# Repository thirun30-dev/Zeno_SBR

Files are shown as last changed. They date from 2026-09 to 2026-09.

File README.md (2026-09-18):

🤖 ZENO — Self-Balancing Robot

<p align="center">
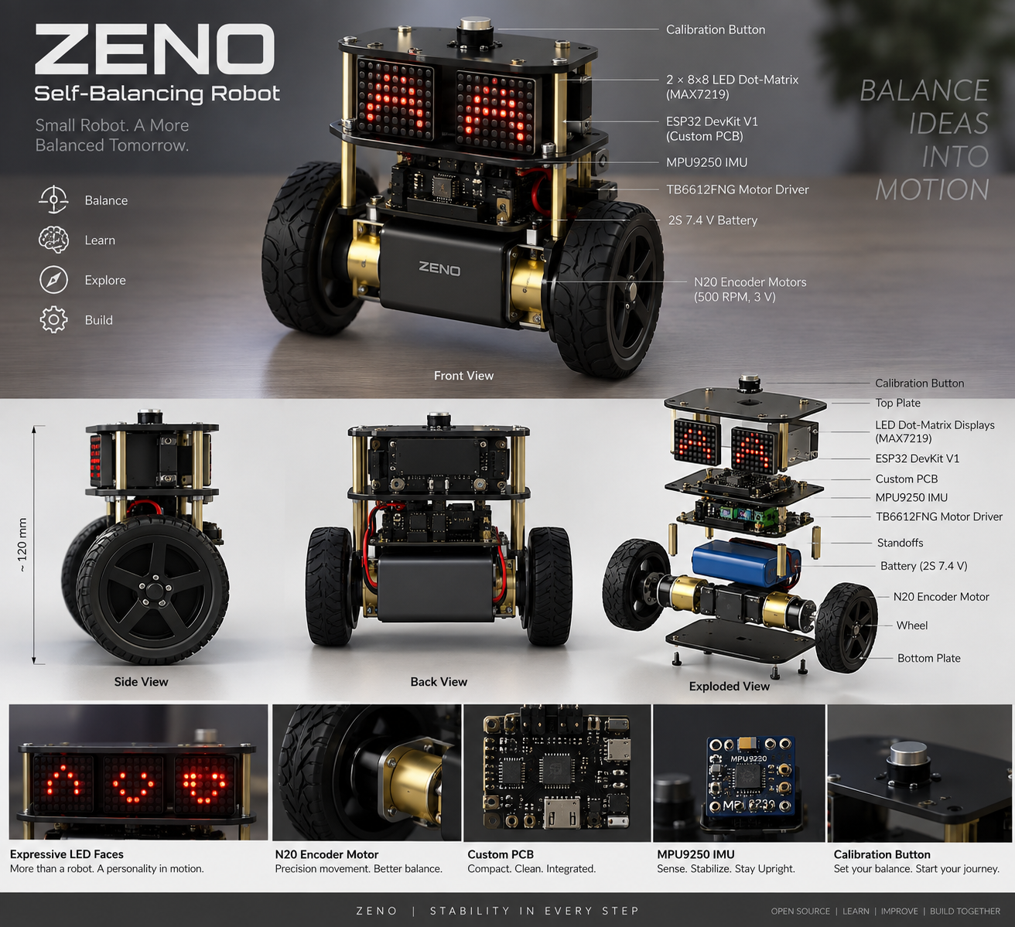
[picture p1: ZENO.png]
ZENO Self-Balancing Robot
  
</p>

<p align="center">
  <b>Balance Ideas Into Motion.</b><br>
  ESP32 • MPU9250 • PID Control • N20 Encoder Motors • TB6612FNG • Custom CAD/PCB • Web Dashboard
</p>

📌 About ZENO

ZENO is a compact two-wheeled self-balancing robot developed as a hands-on platform for embedded systems, feedback control, sensor fusion, motor control, mechanical design, PCB development, and robot–user interaction.

The robot uses an ESP32 DevKit V1 as the main controller, an MPU9250 IMU to estimate body tilt, and two N20 3 V 500 RPM geared DC motors with encoders driven by a TB6612FNG dual motor driver. A PID controller continuously calculates the correction required to keep the robot close to its calibrated upright angle.

The repository also contains the current mechanical design files, 3D-printable parts, a PCB placement/connectivity draft, individual hardware test programs, and the main balancing firmware.

✨ Key Features

Two-wheel real-time self-balancing

ESP32-based embedded control

MPU9250 accelerometer and gyroscope sensing

Complementary-filter angle estimation

PID balance control

N20 encoder motor drive

Serial-command control and PID tuning

IMU calibration routine

Forward, reverse, left, and right movement commands

Automatic motor shutdown beyond a configured fall angle

Modular two-layer mechanical chassis

Custom PCB development files

3D-printable motor cap, base, top deck, and threaded spacers

MAX7219 LED matrix hardware provision for expressive robot eyes

Web-dashboard concept for telemetry, visualization, control, and tuning

🧠 Control Architecture

MPU9250 IMU
    │
    ▼
Accelerometer + Gyroscope
    │
    ▼
Complementary Filter
    │
    ▼
Estimated Pitch Angle
    │
    ▼
Target Angle − Current Angle
    │
    ▼
PID Controller
    │
    ▼
Motor PWM + Direction
    │
    ▼
TB6612FNG Motor Driver
    │
    ▼
N20 Encoder Motors
    │
    └──────── Encoder Feedback ────────┐
                                      │
                                      ▼
                                 ESP32 Control

The current firmware uses starting PID values of:

Kp = 22.0
Ki = 0.0
Kd = 0.85

These are starting values only and must be tuned for the final ZENO mechanical configuration.

🔩 Main Hardware

Component

Specification

Main controller

ESP32 DevKit V1

IMU

MPU9250

Motor driver

TB6612FNG

Motors

2 × N20 3 V 500 RPM geared DC motors

Feedback

Motor encoder signals

Robot eyes

2 × MAX7219 8×8 LED matrix modules

Battery system

Protected 2S battery pack

Nominal battery voltage

7.4 V

Fully charged voltage

8.4 V

ESP32 / display rail

Regulated 5 V

Motor rail

Regulated nominal 3 V

Logic rail

ESP32 3.3 V

PCB outline

Approx. 130 × 77 mm

The motor supply and regulator current capability must be selected using the measured motor stall current. Do not power the stated 3 V motors directly from the raw 2S battery.

🔌 ESP32 Pin Mapping

MPU9250

Signal

ESP32

SDA

GPIO 22

SCL

GPIO 23

I2C address

0x68

TB6612FNG

Signal

ESP32

PWMA

GPIO 25

AIN1

GPIO 26

AIN2

GPIO 27

STBY

GPIO 32

BIN1

GPIO 14

BIN2

GPIO 13

PWMB

GPIO 33

Encoder Input Currently Used by Main Firmware

Signal

ESP32

Encoder A

GPIO 19

Encoder B

GPIO 18

🎮 Serial Commands

The main firmware supports interactive control through the Arduino Serial Monitor.

Command

Function

C

Calibrate IMU

B

Enable balancing

S

Stop balancing

F

Move forward

R

Move backward

L

Turn left

T

Turn right

X

Stop movement

P

Print PID values

I

Increase Kp

i

Decrease Kp

O

Increase Ki

o

Decrease Ki

D

Increase Kd

d

Decrease Kd

⚖️ Calibration and Balancing

Before balancing, place ZENO in the intended upright position and send:

C

The firmware calibrates the IMU and establishes the angle reference. Once calibration is complete, balancing can be enabled with:

B

The robot continuously compares the current tilt with the target angle and applies motor corrections. The current firmware contains a 40° fall-angle safety threshold; when the robot exceeds this angle, motor drive is stopped to reduce uncontrolled motion.

🖥️ ZENO Web Dashboard

ZENO is also being developed with a dedicated web dashboard for a more intuitive robot-monitoring and control experience. The dashboard is intended to complement the ESP32 firmware and Serial Monitor rather than replace firmware-side safety logic.

Planned / Supported Dashboard Areas

Animated 3D ZENO introduction

Light and dark themes

Robot connection state

Balance state

Live pitch / tilt angle

Target angle and PID error

Kp, Ki, and Kd visualization

Left and right motor output

Encoder count / wheel-speed telemetry

IMU acceleration and angular velocity

Battery / power status

Calibration control

Start / stop balancing

Manual movement controls

Emergency-stop interface

Real-time telemetry graphs

PID tuning controls

3D robot orientation visualization

Dashboard Data Flow

ZENO Hardware
     │
     ▼
ESP32 Firmware
     │
     ├── IMU Data
     ├── PID Data
     ├── Encoder Data
     ├── Motor Output
     └── System Status
            │
            ▼
     Wi-Fi / WebSocket
            │
            ▼
      ZENO Dashboard
            │
      ┌─────┴─────┐
      ▼           ▼
 Telemetry      Control

Repository note: the uploaded repository snapshot currently contains the firmware, CAD/3D files, PCB draft, and image assets. The dashboard source is not yet included in this snapshot. Add it under a dedicated Dashboard/ or dashboard/ directory when integrating the web application.

🧱 Mechanical Design

ZENO uses a modular two-layer structure.

Base Layer

The lower section is intended to carry:

N20 motors

Wheels

Battery / battery holder

Motor mounting parts

Structural mounting points

Top Layer

The upper section is intended to carry:

Custom PCB

ESP32 DevKit V1

TB6612FNG

MPU9250

Display modules

Calibration button

The repository includes printable and editable mechanical files for the robot base, top deck, N20 motor cap, deck spacers, and assembly references.

🧩 Repository Structure

Zeno_SBR/
│
├── 3D/
│   ├── 3D print/
│   │   ├── ZENO_base.stl
│   │   ├── top_deck.stl
│   │   ├── N20_single_cap_1.STL
│   │   └── deck_spacer_50mm_M3_threaded.stl
│   │
│   ├── ZENO_Base_Mounting_Holes/
│   ├── ZENO_N20_Single_Cap/
│   ├── ZENO_PCB_Draft/
│   └── ZENO_Top_Layer/
│
├── Code/
│   ├── Motor_Test/
│   │   └── Motor_Test.ino
│   ├── MPU9250/
│   │   └── MPU9250.ino
│   └── ZENO_code/
│       └── ZENO_code.ino
│
└── ZENO.png

After adding the web application, a recommended extension is:

├── Dashboard/
│   ├── src/
│   ├── public/
│   ├── package.json
│   └── README.md

📁 Important Repository Files

Code/Motor_Test/Motor_Test.ino

Used to verify TB6612FNG wiring and basic motor direction/control independently of the balancing loop.

Code/MPU9250/MPU9250.ino

Used to test MPU9250 communication, calibration, and orientation measurement separately.

Code/ZENO_code/ZENO_code.ino

Current integrated ZENO balancing firmware containing IMU acquisition, calibration, complementary filtering, PID calculations, motor control, encoder input, serial commands, and fall protection.

3D/3D print/

Contains the primary STL files intended for fabrication/3D printing.

3D/ZENO_PCB_Draft/

Contains the current KiCad placement and connectivity draft.

⚠️ PCB Development Status

The included ZENO Rev A PCB is a placement/connectivity draft and is currently marked:

UNROUTED — NOT FOR FABRICATION

The PCB files must be fully verified before manufacturing. Required work includes:

Verify physical module footprints and pin order

Confirm motor and encoder electrical requirements

Verify ESP32 footprint spacing

Verify connector families and orientation

Add routing, vias, and copper zones

Add a continuous ground reference

Check ESP32 antenna clearance

Verify motor-current trace width

Complete schematic/ERC verification

Run KiCad DRC

Generate and inspect Gerbers only after validation

Do not submit the current PCB draft directly for fabrication.

🚀 Running the Firmware

Install the ESP32 board package in the Arduino IDE.

Connect the ESP32 DevKit V1.

Open:

Code/ZENO_code/ZENO_code.ino

Select the appropriate ESP32 board and COM/serial port.

Compile and upload the firmware.

Open Serial Monitor.

Keep the robot supported safely with wheels free during initial testing.

Send C to calibrate.

Verify angle direction and motor direction before enabling balance mode.

Tune PID values gradually for the final mechanical build.

🧪 Recommended Testing Sequence

1. Verify regulated power rails
        ↓
2. Test MPU9250 communication
        ↓
3. Run Motor_Test.ino
        ↓
4. Confirm both motor directions
        ↓
5. Verify encoder response
        ↓
6. Upload integrated ZENO firmware
        ↓
7. Calibrate IMU
        ↓
8. Verify tilt-angle direction
        ↓
9. Test balancing while physically supported
        ↓
10. Tune PID parameters
        ↓
11. Perform controlled free-balance tests
        ↓
12. Integrate live dashboard telemetry

🛠️ Development Roadmap

Mechanical base design

Top deck design

N20 motor mounting design

M3 threaded spacer design

MPU9250 test firmware

Motor test firmware

Integrated balancing firmware

Serial-based PID adjustment

Fall-angle protection

Initial PCB placement/connectivity draft

Tune PID on the completed mechanical robot

Validate both motor encoders independently

Complete and route PCB

Fabricate and test custom PCB

Integrate MAX7219 eye animations into main firmware

Add Wi-Fi/WebSocket telemetry

Add dashboard source to repository

Connect dashboard to live ESP32 data

Add battery monitoring

Add OTA firmware updates

Add advanced motion/position control

🎯 Applications and Learning Outcomes

ZENO can be used to explore:

Self-balancing robotics

Inverted-pendulum control

Embedded C/C++ programming

ESP32 development

PID control

Sensor fusion

IMU calibration

DC motor control

Encoder feedback

PCB design

CAD and 3D printing

Power-system integration

Web-based robot telemetry

Human–robot interaction

⚠️ Safety

ZENO contains moving motors and a rechargeable battery system. During development:

Verify regulator outputs before connecting electronics.

Use a protected battery pack.

Keep a physical power-disconnect method available.

Do not test balancing near edges or fragile objects.

Support the chassis during initial PID tuning.

Confirm motor direction before enabling closed-loop balancing.

Do not treat a web-based emergency-stop button as a substitute for hardware power isolation.

📈 Project Status

Active Development

The mechanical design, test firmware, integrated balancing firmware, and initial PCB draft are present in this repository. PID tuning, PCB completion, display integration, wireless telemetry, and web-dashboard integration remain active development areas.

📜 Disclaimer

ZENO is an educational and experimental robotics project. Hardware dimensions, electrical connections, PCB footprints, power-system limits, PID parameters, and software should be independently verified before fabrication or operation.

🤝 Contributions

Suggestions, improvements, testing feedback, and contributions are welcome as the ZENO platform develops.

<p align="center">
  <b>ZENO</b><br>
  <i>Balance Ideas Into Motion.</i>
</p>

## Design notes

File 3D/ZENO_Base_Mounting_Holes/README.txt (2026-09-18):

ZENO BASE LAYER — REV B / PROTOTYPE
All dimensions mm. Designed for two N20 encoder motors, the supplied
76 x 41 x 19 battery holder, and nominal 44 diameter x 18 wide wheels.
This is the lower deck; top deck and motor caps are separate parts.

DIMENSIONS
Plate 124 across axle (X) x 96 fore/aft (Y) x 3 thick; corner radius 6.
Battery pocket internal: 41.8 X x 76.8 Y, centred on base.
Pocket wall 3 thick x 8 above plate; overall wall top Z=11.
Holder rests at Z=3; nominal holder top Z=22.
Wire notch 10 wide in +Y pocket wall, bottom Z=4; open upward.
Strap slots at X=+/-26,Y=0: 3 across X x 12 along Y, through plate.
Motor bracket holes: four diameter 3.2 THRU, X=+/-46,Y=+/-11.
Each bracket has 22 mm hole centre spacing along Y.
Left/right bracket centre separation is 92 mm along X.
Hole coordinates: (-46,-11),(-46,11),(46,-11),(46,11).
M3 clearance, not threaded; use washers and nuts beneath base.
Four top-deck standoff holes: diameter 3.2 at X=+/-52,Y=+/-38;
104 x 76 mounting pattern. M3 clearance, not tapped.
Cable passages at X=+/-39,Y=26: 12 along Y x 5 wide rounded slots.
Origin base centre, Z=0 underside; motor shafts lie along X, nominal Y=0.

MOTOR LAYOUT / LIMITS
Use user's modified N20_single_cap.step.SLDPRT as the intended motor cap.
Its exact geometry/hole positions could not be verified in this workflow.
The fixed 22 mm pitch follows the ORIGINAL single-cap design, not a verified
measurement of the modified SLDPRT. Check hole pitch and motor position in
SolidWorks before printing; these holes provide no slot adjustment.
No replacement motor cap is included. Trial-fit the modified cap before
printing the full deck, or overlay its STEP export on this base in SolidWorks.
Nominal motor location per side: gearbox front X=+/-63, gearbox rear +/-54,
rear motor/encoder envelope ends approximately +/-32. Shaft extends to +/-73.
Suggested steel casing clamp band: |X|=40 to 52, centred on bracket holes at 46.
These positions use the previous motor dimensional image; verify casing,
encoder and cap shape physically. Motor and wheel CAD are NOT included.
Keep wheel inner face outside |X|=64 for nominal 2 mm plate-edge clearance;
actual hub insertion and shaft engagement must be measured, not inferred from
44 x 18 wheel size. Do not operate with inadequate shaft engagement.
If shaft axis is approximately Z=9.1, nominal upright underside clearance is
22-9.1=12.9. With a 48 fore/aft half-length, base-ground contact occurs at
roughly 16 degrees pitch on level ground, ignoring fastener protrusions.
Actual axle height, loaded tyre radius and hub position remain unverified.
This is a geometry prototype, not a tested balancing-robot chassis.

ASSEMBLY
Use a <=10-wide nonconductive strap through pocket-side slots and over holder
so it cannot lift out. Keep the loop beneath the base clear of fasteners.
Route battery wires through +Y notch; two outer slots provide cable routing.
Use washers and nuts with M3 motor-cap bolts; lengths depend on modified cap.
Top-layer supports use four M3 standoffs on 104 x 76 centres. Select height
after top-deck component placement; holder top is already Z=22, so leave
additional clearance for cells, strap, wiring and service access.
Pocket and base share a single 3-thick floor; no stacked floor thickness.

PRINT / FILES
Suggested prototype PETG, bottom-down, 0.2 layers, 4 walls, 40-50% infill;
no supports normally required. Verify bed supports 124 x 96 footprint.
Printed clearance holes may need finishing. Test print mounting/pocket regions
or check parts in CAD before committing full print.
ZENO_base.step: single solid, importable into SolidWorks.
ZENO_base.stl: mm, print orientation bottom-down.
base_with_battery_envelope.step: base + simple 41 x 76 x 19 reference block;
block is not a detailed holder or a printable battery component.
layout.svg: dimensioned schematic top layout; use labelled values, not scaling.
preview.png: geometry preview.
build_base.py + battery_pocket_source.step: reproducible CadQuery source.
Validation: single valid solid, STEP/STL exported; physical fit not tested.

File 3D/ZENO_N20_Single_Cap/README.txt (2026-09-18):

ZENO — SINGLE N20 MOTOR CAP / REV B
Units: mm. Single U-shaped part with two rounded tabs, following user reference.
Replaces the previous two-piece bracket. No separate lower clamp is required:
the flat chassis closes the open side and supports the motor.

DIMENSIONS
Overall: 30 wide x 12 along shaft x 14.9 high.
Internal rectangular channel: 10.4 wide x 12.4 high, open both axial ends.
Wall and roof thickness: 2.5.
Mounting tab thickness: 3.0; rounded end radius 4.0.
Two M3 clearance holes: diameter 3.2 THRU, 22 centre-to-centre.
Hole coordinates: X=-11 and +11, Y=0. Shaft direction is Y.
Chassis contact plane: Z=0. Channel ceiling: Z=12.4.

FIT ASSUMPTIONS — CHECK BEFORE PRINTING
User motor drawing shows 10 x 12 gearbox face, 12.2 max body diameter,
9 gearbox length and 22 +/-1 motor/encoder rear envelope.
The motor casing width across flats is not separately specified. Model assumes
10.0 across flats plus 0.4 total clearance. Height uses 12.2 maximum body
height plus 0.2 clearance. Check actual casing width and height with calipers.
The 12-long cap must fit entirely over steel motor casing, clear of exposed
gears, rear endbell, encoder, connector and any protrusions.
This is a geometrically validated prototype, not a physically tested fit.

INSTALLATION
Place motor casing on chassis with its narrow (assumed 10 mm) dimension
across the cap. Install cap over it, rounded tabs down against chassis.
Use a thin compliant liner/shim to eliminate clearance and create a snug grip.
Do not expect the oversized bare channel alone to clamp the motor securely.
Select liner thickness by actual fit; cap should grip before tabs fully seat.
Use two M3 bolts, washers and nuts; bolt length depends on chassis thickness.
For 3 mm chassis, M3x12 is a starting option: verify washer/nut stack and
thread engagement. Snug evenly without deforming motor casing or tabs.
Confirm motor cannot slide or rotate under operating torque.
Print one cap and test fit before producing the second robot motor mount.

FABRICATION AND FILES
Suggested prototype material PETG; layer 0.2; 4 walls; 50% infill.
STL is oriented roof-down / opening-up, resembling reference photo.
Support is required beneath elevated mounting tabs in this orientation.
Clean supports and finish M3 clearance holes with a 3.2 mm drill if necessary.
STEP uses installed coordinates: tabs at bottom, opening toward chassis.
N20_single_cap.step: solid CAD model importable into SolidWorks.
N20_single_cap.stl: print-oriented mesh in mm.
N20_single_cap.svg: CAD view, not a scale drawing.
preview.png: inverted view exposing internal channel.
build_cap.py: editable CadQuery generator, with explicit fit parameters.

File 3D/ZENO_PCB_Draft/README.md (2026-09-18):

# ZENO Rev A — placement and connectivity draft

**UNROUTED. NOT FOR FABRICATION.** No Gerbers or fabrication release are included. Native KiCad loading and DRC were not available in this environment. Open the board directly in KiCad PCB Editor. Nets provide ratsnest connections; there is no graphical .kicad_sch schematic. The XML netlist is supplementary.

## Mechanical plan
130 × 77 × 1.6 mm, two copper layers. Front is y=77; rear is y=0. Proposed 3.2 mm mounting holes: (5,5), (125,5), (5,72), (125,72) mm. Hole spacing 120 × 67 mm is provisional, not matched to chassis. Module sockets use 1 mm drills and 1.7 mm pads provisionally. No connector body courtyards or final housing geometry have been validated. The preview is a placement drawing, not a rendering of a finished routed PCB.

## Electrical decisions
External regulated +5 V enters J7; external regulated nominal 3 V motor power enters J8. Raw 2S battery must not enter either connector. Use upstream protection and regulator current capacity appropriate to measured loads. Do not simultaneously connect external 5 V and USB until the actual DevKit power-path isolation is checked. VM and +5 V share ground but are not connected together. TB6612 logic VCC is +3V3. Check driver suitability against motor stall current and thermal conditions; no stall-current validation has been performed.

Encoder supply is provisionally 3.3 V. If encoder requires 5 V, redesign supply and level conversion before connection. GPIO34/35/36/39 are input-only; external pull-up footprints are provided. Do not infer cable pin order from colours. Motor minus is a bridge output, not ground.

Displays use three 5 V SN74AHCT125 buffer channels. Eye 1 DOUT must return through J5 to eye 2 DIN at J4. Both displays share CLK and CS. This additional return connection is required for independent eyes in a daisy chain. Alternatively wire module-to-module and revise the harness accordingly.

Calibration: J6 pins 1 COM/GND, 2 NO/GPIO4, 3 LED+/5V, 4 LED-/GND. NC unused. LED continuously on with power if purchased LED supports 5 V. Firmware must debounce and allow calibration only when stationary with motor outputs disabled. This button is not a battery disconnect or emergency stop.

IMU: AD0 low selects 0x68 for compatible devices; NCS held high for I2C, FSYNC low. EDA/ECL/INT unused. Verify sensor identity, VCC regulator dropout, and bus pull-ups on actual board. Optional carrier I2C pull-ups R7/R8 are DNP by default.

## Before routing and fabrication
1. Measure ESP32 row spacing (assumed 25.4 mm), TB6612 row spacing (assumed 15.24 mm), and IMU pitch (assumed 2.54 mm). Confirm module face/orientation against every net, especially TB6612 photograph.
2. Identify exact six-pin JST family, pitch, mating PCB header and cable orientation. Current J1/J2 pads are 2.0 mm placeholders, not validated connector footprints.
3. Measure standoffs and switch chassis clearance; confirm motor/encoder voltage and stall current.
4. Replace provisional footprints with verified body outlines/courtyards, add actual ESP32 antenna copper/component keepout on both sides and maintain USB access.
5. Route motor paths short and wide, away from IMU and I2C; size copper for measured current and copper weight. Provide ground plane and local decoupling. This draft has ZERO tracks, vias, zones, or enforced keepouts.
6. Create/verify graphical schematic and ERC, route every net, then run KiCad DRC and review fabrication outputs. Print footprint page at 1:1 and physically test-fit before ordering.

## Sources
- ESP32: https://www.espressif.com/sites/default/files/documentation/esp32_datasheet_en.pdf
- TB6612FNG: https://www.sparkfun.com/datasheets/Robotics/TB6612FNG.pdf
- MAX7219: https://www.analog.com/media/en/technical-documentation/data-sheets/MAX7219-MAX7221.pdf
- SN74AHCT125: https://www.ti.com/lit/ds/symlink/sn74ahct125.pdf
Module pin labels were taken from user-supplied photographs; module dimensions were not supplied.

## Parts and pad assignments

### U1 — ESP32_DEVKIT_V1_30PIN_ASSUMED
Component-side top view, USB at rear. Left row VIN..EN; right row 3V3..D23. 25.4 mm row spacing and 2.54 mm pitch ASSUMED; compare physical board before fabrication.

| Pad | Net |
|---:|---|
| 1 | +5V |
| 2 | GND |
| 3 | DISP_DIN |
| 4 | NC_D12 |
| 5 | PWMB |
| 6 | AIN2 |
| 7 | AIN1 |
| 8 | PWMA |
| 9 | DISP_CS |
| 10 | DISP_CLK |
| 11 | ENC_L_B |
| 12 | ENC_L_A |
| 13 | ENC_R_B |
| 14 | ENC_R_A |
| 15 | NC_EN |
| 16 | +3V3 |
| 17 | GND |
| 18 | NC_D15 |
| 19 | NC_D2 |
| 20 | CAL |
| 21 | NC_RX2 |
| 22 | NC_TX2 |
| 23 | NC_D5 |
| 24 | BIN1 |
| 25 | BIN2 |
| 26 | SDA |
| 27 | NC_RX0 |
| 28 | NC_TX0 |
| 29 | SCL |
| 30 | STBY |

### U2 — TB6612FNG_MODULE_ASSUMED
Pin sequence from supplied labelled face; verify which face is upward when plugged in. 15.24 mm row spacing ASSUMED.

| Pad | Net |
|---:|---|
| 1 | PWMA |
| 2 | AIN2 |
| 3 | AIN1 |
| 4 | STBY |
| 5 | BIN1 |
| 6 | BIN2 |
| 7 | PWMB |
| 8 | GND |
| 9 | VM |
| 10 | +3V3 |
| 11 | GND |
| 12 | M_L_P |
| 13 | M_L_N |
| 14 | M_R_N |
| 15 | M_R_P |
| 16 | GND |

### U3 — MPU9250_6500_MODULE_ASSUMED
2.54 mm pitch ASSUMED; AD0 low, NCS high, FSYNC low. Module VCC regulator/dropout must be checked; sensor identity unconfirmed.

| Pad | Net |
|---:|---|
| 1 | +3V3 |
| 2 | GND |
| 3 | SCL |
| 4 | SDA |
| 5 | NC_EDA |
| 6 | NC_ECL |
| 7 | GND |
| 8 | NC_INT |
| 9 | +3V3 |
| 10 | GND |

### J1 — LEFT_MOTOR_JST_PH_6_ASSUMED
2.0 mm pitch PLACEHOLDER, not validated JST housing. Cable pin order is proposed, not measured.

| Pad | Net |
|---:|---|
| 1 | M_L_N |
| 2 | M_L_P |
| 3 | +3V3 |
| 4 | GND |
| 5 | ENC_L_A |
| 6 | ENC_L_B |

### J2 — RIGHT_MOTOR_JST_PH_6_ASSUMED
Same assumptions as J1; encoder supply and logic must support 3.3 V.

| Pad | Net |
|---:|---|
| 1 | M_R_N |
| 2 | M_R_P |
| 3 | +3V3 |
| 4 | GND |
| 5 | ENC_R_A |
| 6 | ENC_R_B |

### J3 — EYE_INPUT_5PIN

| Pad | Net |
|---:|---|
| 1 | +5V |
| 2 | GND |
| 3 | DIN_5V |
| 4 | CS_5V |
| 5 | CLK_5V |

### J4 — EYE_INPUT_5PIN

| Pad | Net |
|---:|---|
| 1 | +5V |
| 2 | GND |
| 3 | CHAIN_DOUT |
| 4 | CS_5V |
| 5 | CLK_5V |

### J5 — EYE1_DOUT_RETURN
Connect eye 1 output DOUT here. J4 DIN gets this net, never ESP32 input.

| Pad | Net |
|---:|---|
| 1 | CHAIN_DOUT |
| 2 | GND |

### J6 — REAR_CAL_BUTTON
COM,NO,LED+,LED-. NC unused. Actual switch terminals must be identified.

| Pad | Net |
|---:|---|
| 1 | GND |
| 2 | CAL |
| 3 | +5V |
| 4 | GND |

### J7 — REGULATED_5V_INPUT
External regulated 5 V only; no raw battery. Fuse and reverse-polarity protection upstream.

| Pad | Net |
|---:|---|
| 1 | +5V |
| 2 | GND |

### J8 — REGULATED_MOTOR_INPUT
External regulated nominal 3 V for stated 3 V motors. Supply/driver current suitability pending stall current.

| Pad | Net |
|---:|---|
| 1 | VM |
| 2 | GND |

### U4 — SN74AHCT125N_DIP14
PCB pad numbering is explicit DIP numbering. 5 V supply, three channels active, fourth disabled.

| Pad | Net |
|---:|---|
| 1 | GND |
| 2 | DISP_DIN |
| 3 | DIN_5V |
| 4 | GND |
| 5 | DISP_CS |
| 6 | CS_5V |
| 7 | GND |
| 14 | +5V |
| 13 | +5V |
| 12 | GND |
| 11 | NC_BUF_OUT |
| 10 | GND |
| 9 | DISP_CLK |
| 8 | CLK_5V |

### R1 — 10k
Encoder pull-ups populate only for verified compatible encoder outputs.

| Pad | Net |
|---:|---|
| 1 | ENC_L_A |
| 2 | +3V3 |

### R2 — 10k
Encoder pull-ups populate only for verified compatible encoder outputs.

| Pad | Net |
|---:|---|
| 1 | ENC_L_B |
| 2 | +3V3 |

### R3 — 10k
Encoder pull-ups populate only for verified compatible encoder outputs.

| Pad | Net |
|---:|---|
| 1 | ENC_R_A |
| 2 | +3V3 |

### R4 — 10k
Encoder pull-ups populate only for verified compatible encoder outputs.

| Pad | Net |
|---:|---|
| 1 | ENC_R_B |
| 2 | +3V3 |

### R5 — 10k
Encoder pull-ups populate only for verified compatible encoder outputs.

| Pad | Net |
|---:|---|
| 1 | CAL |
| 2 | +3V3 |

### R6 — 10k_STBY_PULLDOWN

| Pad | Net |
|---:|---|
| 1 | STBY |
| 2 | GND |

### C1 — 100nF

| Pad | Net |
|---:|---|
| 1 | +5V |
| 2 | GND |

### C2 — 100nF

| Pad | Net |
|---:|---|
| 1 | +3V3 |
| 2 | GND |

### C3 — 100nF

| Pad | Net |
|---:|---|
| 1 | +3V3 |
| 2 | GND |

### C4 — 100nF

| Pad | Net |
|---:|---|
| 1 | VM |
| 2 | GND |

### C5 — 470uF_10V
Polarized: pad 1 positive; 8 mm diameter placeholder.

| Pad | Net |
|---:|---|
| 1 | VM |
| 2 | GND |

### C6 — 220uF_10V
Polarized: pad 1 positive; 8 mm diameter placeholder.

| Pad | Net |
|---:|---|
| 1 | +5V |
| 2 | GND |

### R7 — 4k7_DNP
Optional I2C pull-up; normally DNP if module already provides pull-ups to 3.3 V.

| Pad | Net |
|---:|---|
| 1 | SDA |
| 2 | +3V3 |

### R8 — 4k7_DNP
Optional I2C pull-up; normally DNP if module already provides pull-ups to 3.3 V.

| Pad | Net |
|---:|---|
| 1 | SCL |
| 2 | +3V3 |

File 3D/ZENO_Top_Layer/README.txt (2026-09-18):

ZENO TOP LAYER — REV A / PROVISIONAL PCB HOLE PATTERN
All dimensions mm. This design adds a top deck, four integral PCB standoffs,
and four separate inter-deck spacers matching the existing base.

USER DIMENSIONS
PCB: 130 x 77 x 5. Treated as a rectangular envelope, not a verified board
outline with traces, underside components or measured mounting holes.
Two complete dot-matrix modules: each 51 x 32 x 14.
Separate user value 32 x 32 x 80 conflicts with the complete module envelope.
It has NOT been silently corrected to 8.0. Confirm that value before making
display recesses, face panels or mounting brackets.

TOP DECK
144 along axle X x 100 fore/aft Y x 3 thick; corner radius 6.
Four integral PCB supports: diameter 8, height 8 above deck top.
Support holes diameter 3.2 THRU support and plate, for M3 bolts/nuts.
PCB hole coordinates X=+/-60,Y=+/-33.5, pattern 120 x 67.
THIS PATTERN IS ASSUMED: holes inset 5 from each PCB edge. PCB dimensions
alone do not establish actual mounting holes. Verify or edit source before
fabrication. Do not drill an assembled PCB without checking copper/components.
Four frame attachment holes diameter 3.2 at X=+/-52,Y=+/-38,
pattern 104 x 76 matching the base layer.
Two cable slots 18 x 5 along X, centred X=+/-25,Y=44, outside PCB footprint.
Origin deck centre, local underside Z=0. Local support top Z=11.

FRAME SPACERS
Print 4 copies of deck_spacer_32mm.stl.
Each spacer diameter 10, length 32, through bore diameter 3.2.
These are hollow spacers for through bolts, not threaded pillars.
Use four M3 bolts passing through base, spacer and top deck, with washers/nuts.
Plate/spacer stack is 3+32+3=38; M3x45 is a starting length; verify actual
washer/nut stack and thread protrusion. Assemble frame before installing PCB.
PCB mounting stack: deck3 + support8 + PCB5 =16; M3x22 with washers/nuts is
an initial option. Confirm actual board thickness and underside clearance.
Use insulating washers as needed for the actual board layout.

INSTALLED HEIGHTS — ALL FROM BASE UNDERSIDE
Base top: Z=3.
Battery-holder envelope top: Z=22.
Top deck underside: Z=35; top surface Z=38.
PCB underside on supports: Z=46; envelope top Z=51.
Two flat display reference blocks: Z=51 to65; placement is illustrative only.
Battery-holder envelope-to-deck clearance: 13; verify installed cells, strap,
wires and access for removal. Component pin heights are not supplied.
Nominal 44 mm wheel top from prior assumed axle Z=9.1: Z=31.1.
Top deck underside has nominal 3.9 clearance above wheel; actual tyre, hub,
axle, fastener protrusions and motor cap geometry require assembly checking.

DISPLAY PLACEMENT
Assembly shows two modules flat, 32 along X x 51 along Y x 14 high, centred
X=-22 and +22,Y=0, with 12 between module envelopes. Their physical fasteners,
connectors, cables and other PCB components are not modelled. These are NOT
verified mounts or detailed module CAD. No display-specific holes were guessed.
PCB can be populated differently after actual component layout is established.

FILES / PRINTING
1 x top_deck.stl: print underside-down; 4 PCB supports are integral.
4 x deck_spacer_32mm.stl: print upright.
STEP files: same solid geometry, importable into SolidWorks.
two_layer_layout.step: base reference + top deck + four frame spacers + simple
PCB and two display envelopes. Envelopes are NOT parts to print.
base_reference.step: copy of previous base for assembly reference only.
build_top.py: CadQuery generator; pattern is explicit and editable.
layout.svg: dimensioned schematic top view and height schedule.
preview.png: top deck and frame spacers in an exploded view.
Suggested prototype PETG, 0.2 layers, 4 walls, 40-50% infill; spacers 100%.
No supports normally required. Finish clearance bores if printer undersizes.
Validation: deck and spacer are single valid solids; exported to STEP/STL.
Physical fit, PCB layout, display mounts and loaded rigidity remain untested.

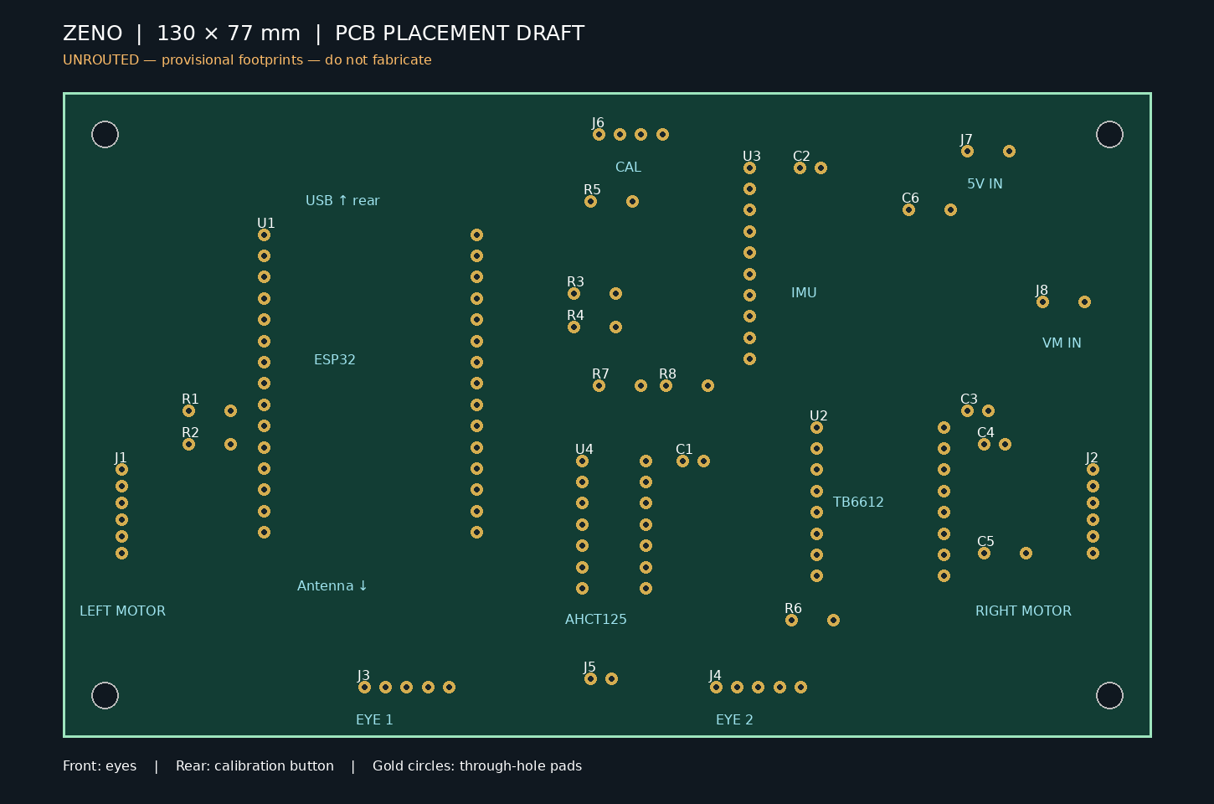
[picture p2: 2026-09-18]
3D/ZENO_PCB_Draft/ZENO_layout_preview.png

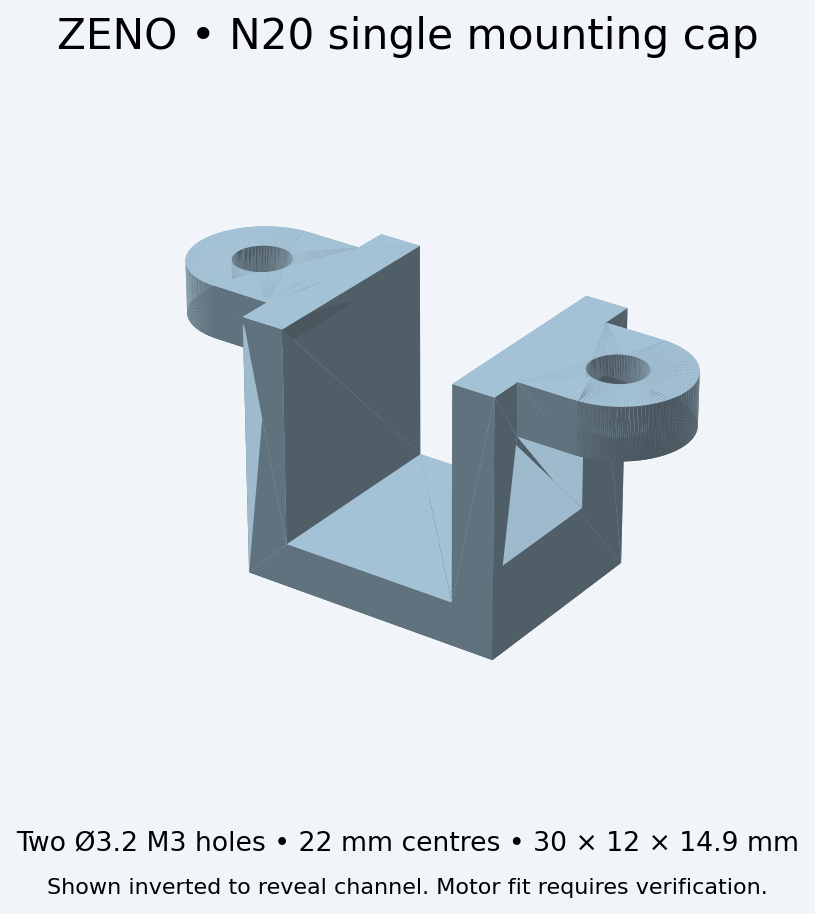
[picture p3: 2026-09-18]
3D/ZENO_N20_Single_Cap/preview.png

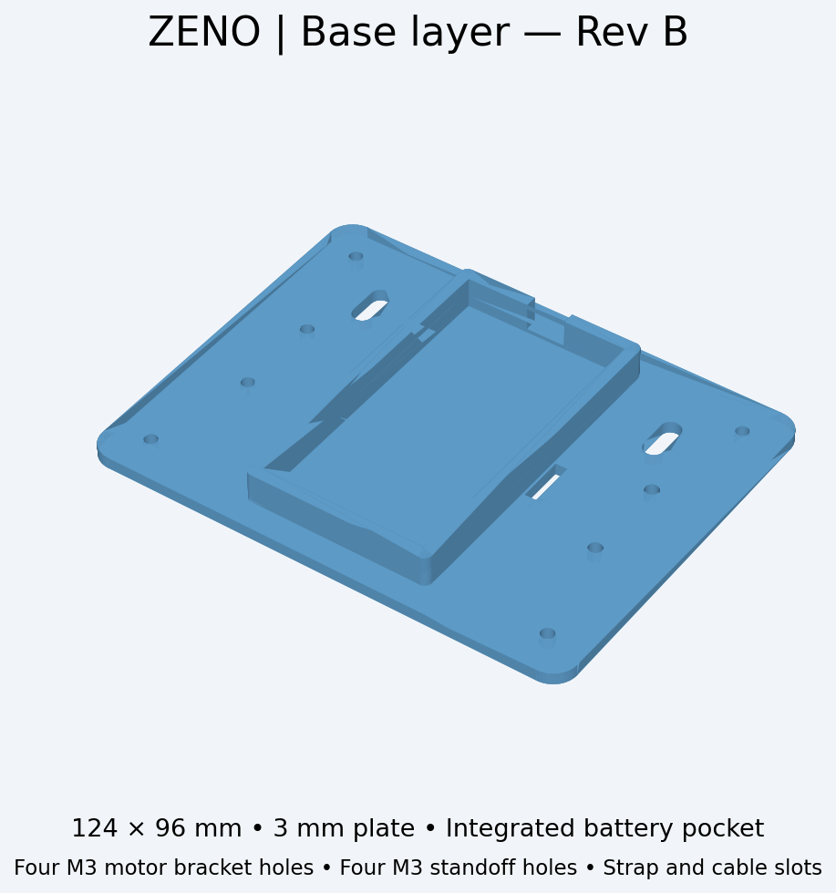
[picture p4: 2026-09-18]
3D/ZENO_Base_Mounting_Holes/preview.png

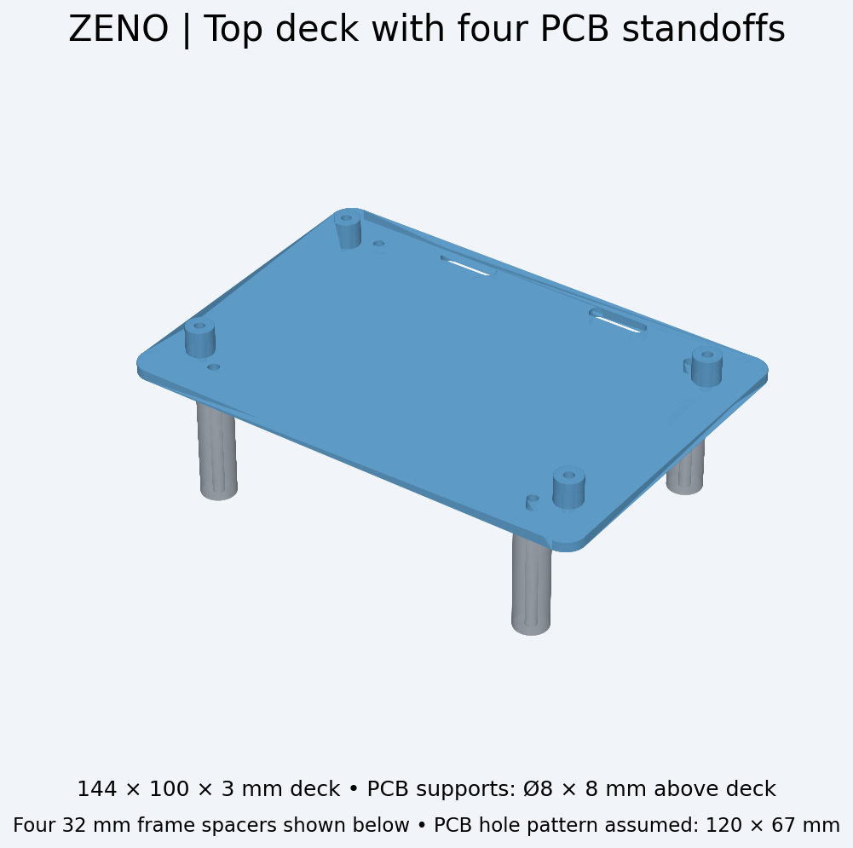
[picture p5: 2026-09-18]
3D/ZENO_Top_Layer/preview.png

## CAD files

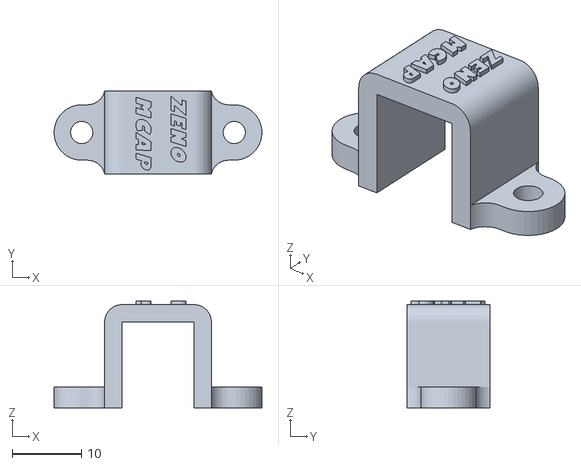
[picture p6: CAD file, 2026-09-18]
3D/3D print/N20_single_cap_1.STL
30.0 x 12.0 x 15.4

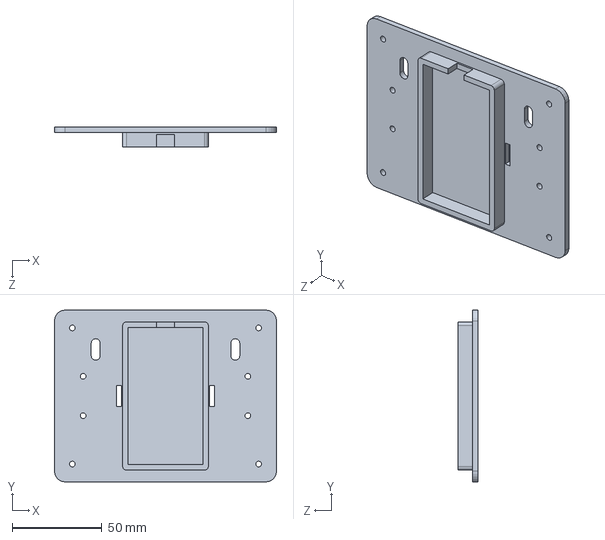
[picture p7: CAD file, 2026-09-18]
3D/ZENO_Base_Mounting_Holes/ZENO_base.step.SLDPRT
124.0 x 96.0 x 11.0 mm

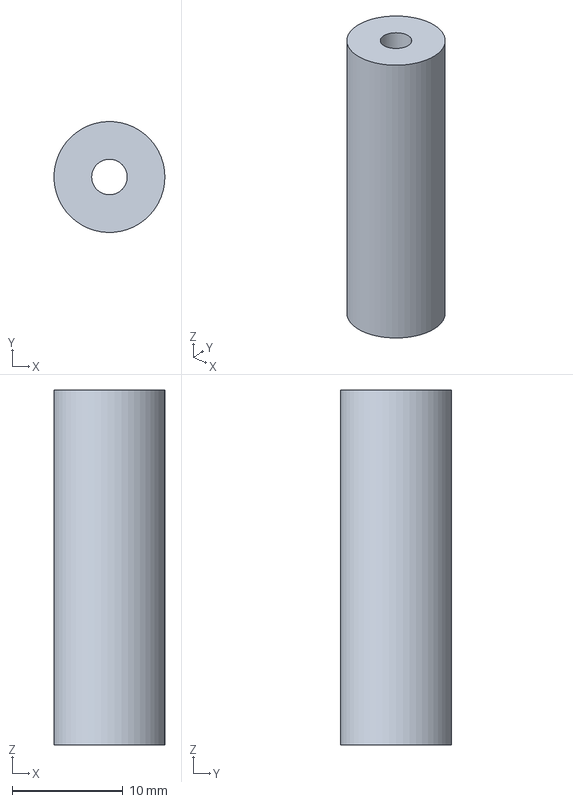
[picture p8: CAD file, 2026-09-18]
3D/ZENO_Top_Layer/deck_spacer_32mm.step
9.99 x 10.00 x 32.0 mm

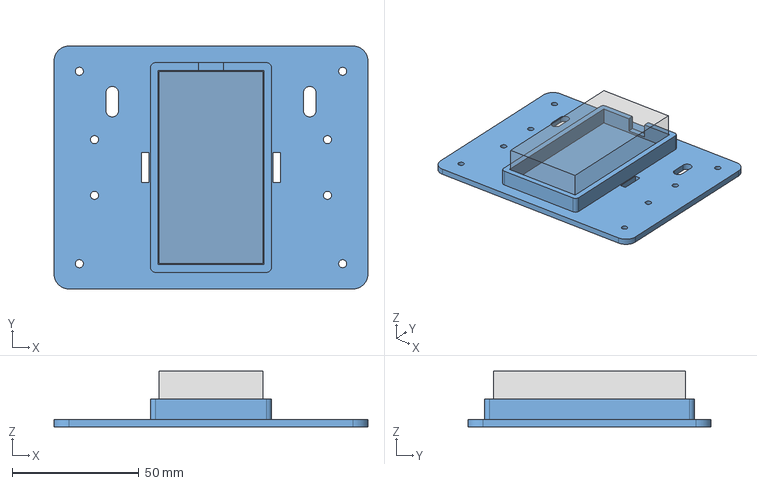
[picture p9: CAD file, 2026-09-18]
3D/ZENO_Base_Mounting_Holes/base_with_battery_envelope.step
124.0 x 96.0 x 22.0 mm
base
battery_holder_ENVELOPE

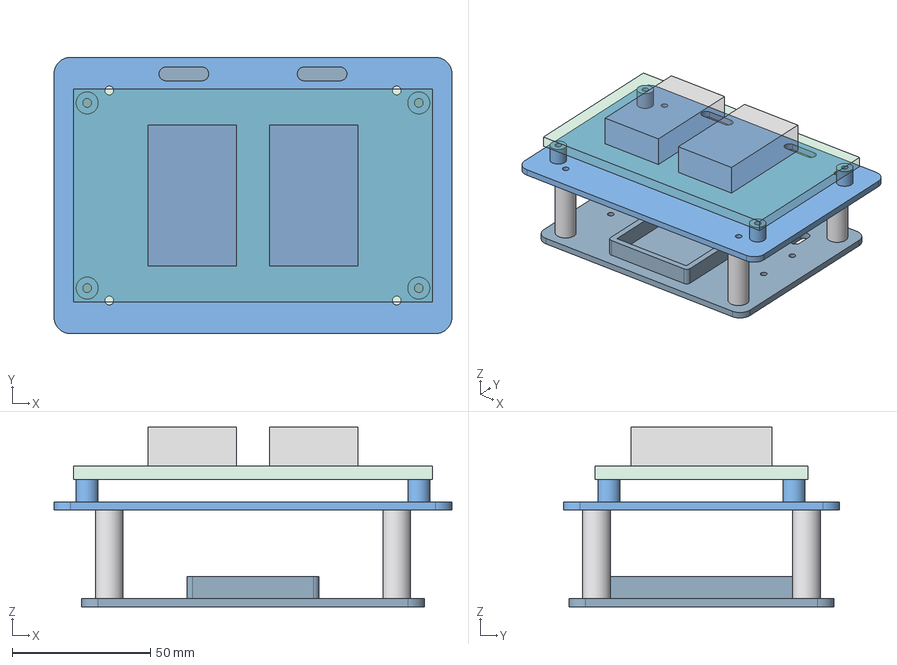
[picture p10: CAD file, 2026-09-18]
3D/ZENO_Top_Layer/two_layer_layout.step
144.0 x 100.0 x 65.0 mm
top_deck
base_reference
frame_spacer_1
frame_spacer_2
frame_spacer_3
frame_spacer_4
PCB_ENVELOPE_130x77x5
DISPLAY_ENVELOPE_1_32x51x14
DISPLAY_ENVELOPE_2_32x51x14

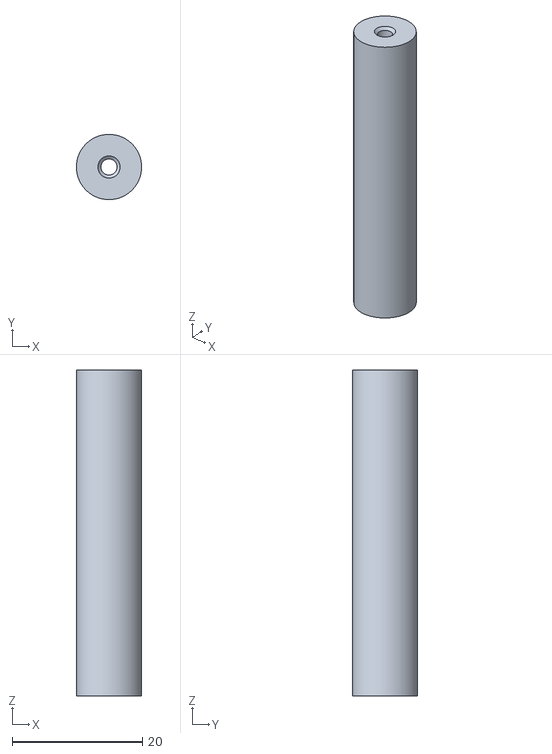
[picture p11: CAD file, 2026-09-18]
3D/3D print/deck_spacer_50mm_M3_threaded.stl
10.0 x 10.00 x 50.0

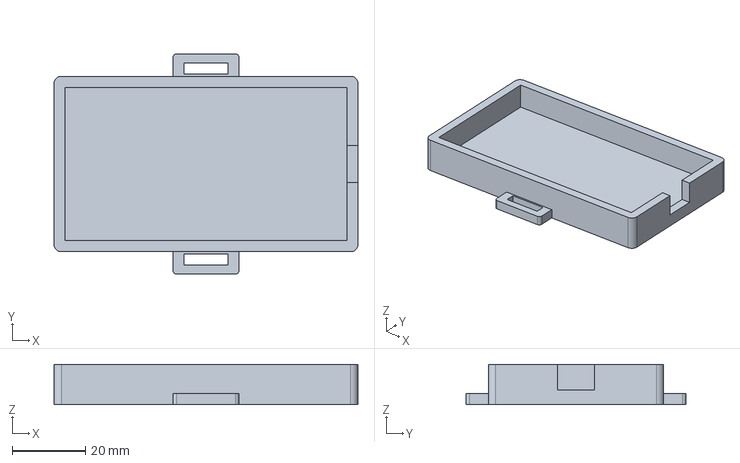
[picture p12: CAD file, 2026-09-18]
3D/ZENO_Base_Mounting_Holes/battery_pocket_source.step
82.8 x 60.0 x 11.0 mm

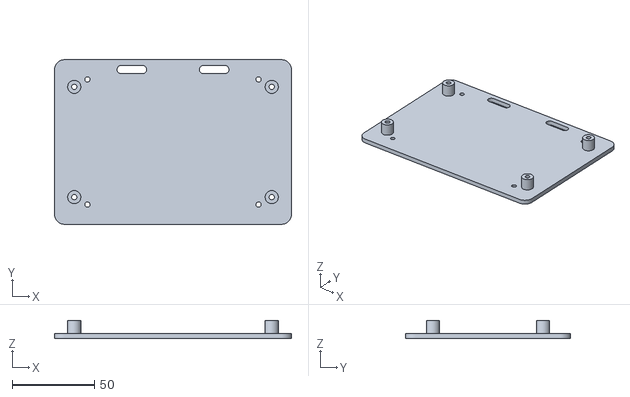
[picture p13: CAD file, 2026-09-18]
3D/3D print/top_deck.stl
144.0 x 100.0 x 11.0

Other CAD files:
3D/3D print/ZENO_base.stl
3D/ZENO_N20_Single_Cap/N20_single_cap.step.SLDPRT
3D/ZENO_N20_Single_Cap/N20_single_cap.step
3D/ZENO_Top_Layer/base_reference.step
3D/ZENO_Base_Mounting_Holes/ZENO_base.step
3D/ZENO_Top_Layer/top_deck.step
3D/ZENO_Top_Layer/deck_spacer_50mm.step
3D/ZENO_Base_Mounting_Holes/ZENO_base.stl
3D/ZENO_N20_Single_Cap/N20_single_cap.stl
3D/ZENO_Top_Layer/deck_spacer_32mm.stl
3D/ZENO_Top_Layer/deck_spacer_50mm.STL

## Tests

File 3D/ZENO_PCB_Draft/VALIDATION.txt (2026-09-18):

26 electrical footprints; 4 mounting holes; 29 named nets.
Pad coordinates checked inside board outline. XML parsed and PCB parentheses balanced.
No KiCad parser, ERC, DRC, electrical operation, or mechanical fit validation performed.
Unrouted: zero copper tracks. Do not fabricate.

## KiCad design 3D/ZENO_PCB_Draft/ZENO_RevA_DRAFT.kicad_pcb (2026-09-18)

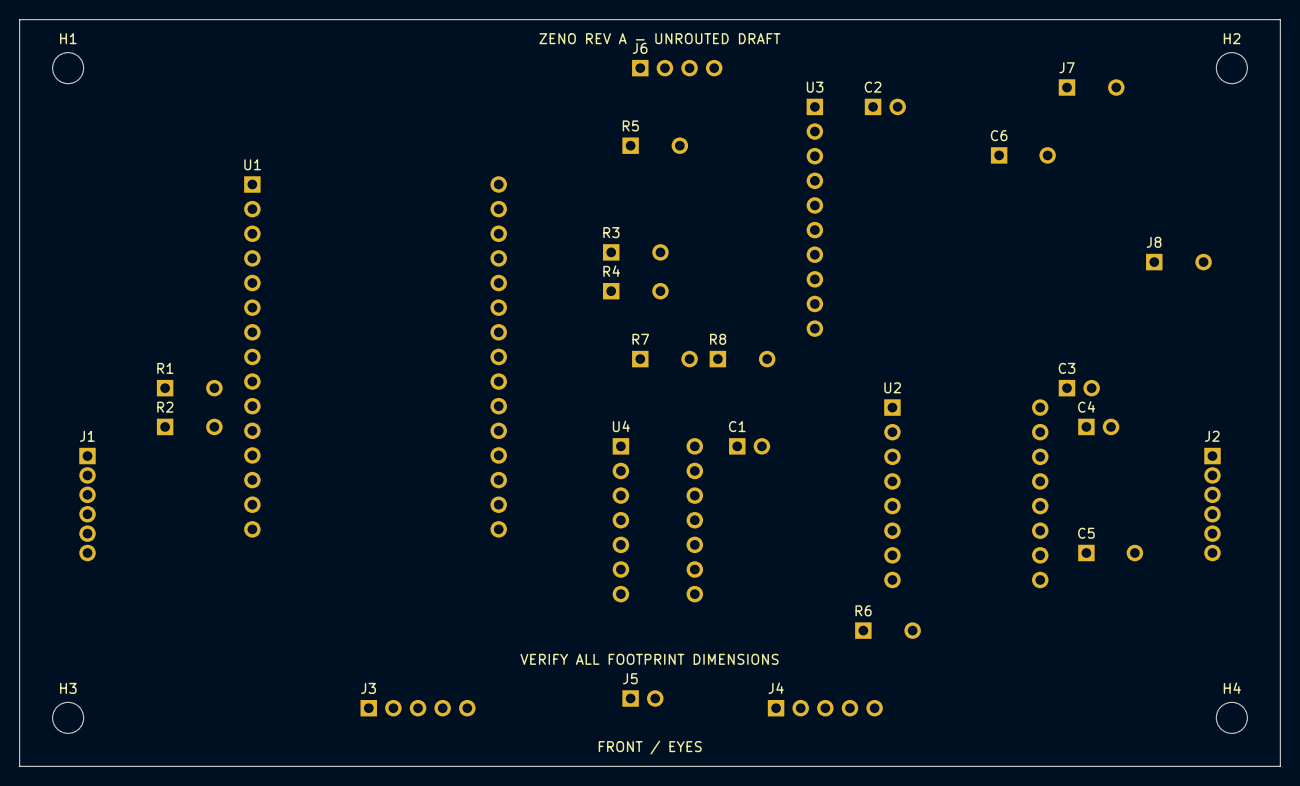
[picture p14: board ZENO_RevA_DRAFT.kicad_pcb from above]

Board: 2 copper layers, 130.0 x 77.0 mm, 30 parts (0 on the bottom side), 29 nets, no tracks yet.

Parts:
C1, C2, C3, C4: 100nF
C5: 470uF_10V
C6: 220uF_10V
H1, H2, H3, H4: M3_NPTH
J1: LEFT_MOTOR_JST_PH_6_ASSUMED
J2: RIGHT_MOTOR_JST_PH_6_ASSUMED
J3, J4: EYE_INPUT_5PIN
J5: EYE1_DOUT_RETURN
J6: REAR_CAL_BUTTON
J7: REGULATED_5V_INPUT
J8: REGULATED_MOTOR_INPUT
R1, R2, R3, R4, R5: 10k
R6: 10k_STBY_PULLDOWN
R7, R8: 4k7_DNP
U1: ESP32_DEVKIT_V1_30PIN_ASSUMED
U2: TB6612FNG_MODULE_ASSUMED
U3: MPU9250_6500_MODULE_ASSUMED
U4: SN74AHCT125N_DIP14

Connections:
+3V3: C2.1, C3.1, J1.3, J2.3, R1.2, R2.2, R3.2, R4.2, R5.2, R7.2, R8.2, U1.16, U2.10, U3.1, U3.9
+5V: C1.1, C6.1, J3.1, J4.1, J6.3, J7.1, U1.1, U4.13, U4.14
AIN1: U1.7, U2.3
AIN2: U1.6, U2.2
BIN1: U1.24, U2.5
BIN2: U1.25, U2.6
CAL: J6.2, R5.1, U1.20
CHAIN_DOUT: J4.3, J5.1
CLK_5V: J3.5, J4.5, U4.8
CS_5V: J3.4, J4.4, U4.6
DIN_5V: J3.3, U4.3
DISP_CLK: U1.10, U4.9
DISP_CS: U1.9, U4.5
DISP_DIN: U1.3, U4.2
ENC_L_A: J1.5, R1.1, U1.12
ENC_L_B: J1.6, R2.1, U1.11
ENC_R_A: J2.5, R3.1, U1.14
ENC_R_B: J2.6, R4.1, U1.13
GND: C1.2, C2.2, C3.2, C4.2, C5.2, C6.2, J1.4, J2.4, J3.2, J4.2, J5.2, J6.1, J6.4, J7.2, J8.2, R6.2, U1.2, U1.17, U2.8, U2.11, U2.16, U3.2, U3.7, U3.10, U4.1, U4.4, U4.7, U4.10, U4.12
M_L_N: J1.1, U2.13
M_L_P: J1.2, U2.12
M_R_N: J2.1, U2.14
M_R_P: J2.2, U2.15
PWMA: U1.8, U2.1
PWMB: U1.5, U2.7
SCL: R8.1, U1.29, U3.3
SDA: R7.1, U1.26, U3.4
STBY: R6.1, U1.30, U2.4
VM: C4.1, C5.1, J8.1, U2.9

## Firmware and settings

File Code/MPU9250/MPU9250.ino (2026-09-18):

#include <Wire.h>
#include <MPU9250_asukiaaa.h>

// =====================================================
//                    ZENO
//     ESP32 SELF BALANCING ROBOT
//
// ESP32 + MPU9250 + TB6612FNG
// 2 x N20 Encoder Motors
// =====================================================


// =====================================================
// MPU9250
// =====================================================

#define MPU_SDA 22
#define MPU_SCL 23

MPU9250_asukiaaa mpu;


// =====================================================
// TB6612FNG MOTOR DRIVER
// =====================================================

// LEFT MOTOR
#define PWMA 25
#define AIN1 26
#define AIN2 27

// RIGHT MOTOR
#define PWMB 33
#define BIN1 14
#define BIN2 13

#define STBY 32


// =====================================================
// ENCODERS
// =====================================================

// LEFT
#define LEFT_ENC_A 34
#define LEFT_ENC_B 35

// RIGHT
#define RIGHT_ENC_A 19
#define RIGHT_ENC_B 18


volatile long leftEncoderCount = 0;
volatile long rightEncoderCount = 0;


// =====================================================
// PWM SETTINGS
// =====================================================

#define PWM_FREQUENCY 20000
#define PWM_RESOLUTION 8

#define MAX_PWM 255

/*
  N20 motors often require some minimum PWM
  before they start moving.

  Start low during initial testing.
*/
int MIN_PWM = 35;


// =====================================================
// BALANCE PARAMETERS
// =====================================================

/*
   IMPORTANT:

   These are STARTING values only.

   PID MUST be tuned on your actual robot.
*/

float Kp = 18.0;
float Ki = 0.0;
float Kd = 0.65;


// Desired upright angle

float balanceSetpoint = 0.0;


// PID variables

float error = 0;
float previousError = 0;

float integral = 0;
float derivative = 0;

float pidOutput = 0;


// =====================================================
// IMU VARIABLES
// =====================================================

float ax = 0;
float ay = 0;
float az = 0;

float gx = 0;
float gy = 0;
float gz = 0;


// Gyroscope bias

float gyroOffsetX = 0;
float gyroOffsetY = 0;
float gyroOffsetZ = 0;


// Angle

float accelAngle = 0;
float balanceAngle = 0;


// =====================================================
// COMPLEMENTARY FILTER
// =====================================================

const float FILTER_ALPHA = 0.98;


// =====================================================
// LOOP TIMING
// =====================================================

// 5 ms = 200 Hz

const unsigned long CONTROL_PERIOD_US = 5000;

unsigned long previousControlTime = 0;


// =====================================================
// SAFETY
// =====================================================

const float FALL_ANGLE = 35.0;

// robot will only arm when reasonably upright

const float ARM_ANGLE = 8.0;

bool robotArmed = false;


// =====================================================
// MOTOR ORIENTATION
// =====================================================

/*
   Because the two motors are physically mounted
   opposite each other, one motor may need reversing.

   Change these if necessary.
*/

const int LEFT_MOTOR_DIRECTION = 1;
const int RIGHT_MOTOR_DIRECTION = 1;


// =====================================================
// ENCODER ISR
// =====================================================

void IRAM_ATTR leftEncoderISR()
{
  bool A = digitalRead(LEFT_ENC_A);
  bool B = digitalRead(LEFT_ENC_B);

  if (A == B)
  {
    leftEncoderCount++;
  }
  else
  {
    leftEncoderCount--;
  }
}


void IRAM_ATTR rightEncoderISR()
{
  bool A = digitalRead(RIGHT_ENC_A);
  bool B = digitalRead(RIGHT_ENC_B);

  if (A == B)
  {
    rightEncoderCount++;
  }
  else
  {
    rightEncoderCount--;
  }
}


// =====================================================
// LEFT MOTOR
// =====================================================

void setLeftMotor(int speed)
{
  speed *= LEFT_MOTOR_DIRECTION;

  speed = constrain(speed, -255, 255);


  if (speed > 0)
  {
    digitalWrite(AIN1, HIGH);
    digitalWrite(AIN2, LOW);

    ledcWrite(PWMA, speed);
  }

  else if (speed < 0)
  {
    digitalWrite(AIN1, LOW);
    digitalWrite(AIN2, HIGH);

    ledcWrite(PWMA, abs(speed));
  }

  else
  {
    digitalWrite(AIN1, LOW);
    digitalWrite(AIN2, LOW);

    ledcWrite(PWMA, 0);
  }
}


// =====================================================
// RIGHT MOTOR
// =====================================================

void setRightMotor(int speed)
{
  speed *= RIGHT_MOTOR_DIRECTION;

  speed = constrain(speed, -255, 255);


  if (speed > 0)
  {
    digitalWrite(BIN1, HIGH);
    digitalWrite(BIN2, LOW);

    ledcWrite(PWMB, speed);
  }

  else if (speed < 0)
  {
    digitalWrite(BIN1, LOW);
    digitalWrite(BIN2, HIGH);

    ledcWrite(PWMB, abs(speed));
  }

  else
  {
    digitalWrite(BIN1, LOW);
    digitalWrite(BIN2, LOW);

    ledcWrite(PWMB, 0);
  }
}


// =====================================================
// STOP MOTORS
// =====================================================

void stopMotors()
{
  setLeftMotor(0);
  setRightMotor(0);
}


// =====================================================
// APPLY BALANCE MOTOR COMMAND
// =====================================================

void driveBalance(int motorCommand)
{
  motorCommand = constrain(
      motorCommand,
      -MAX_PWM,
      MAX_PWM
  );


  // Dead zone compensation

  if (motorCommand > 0 &&
      motorCommand < MIN_PWM)
  {
    motorCommand = MIN_PWM;
  }

  else if (motorCommand < 0 &&
           motorCommand > -MIN_PWM)
  {
    motorCommand = -MIN_PWM;
  }


  /*
     Both motors receive the same logical command.

     If one wheel physically spins backwards because
     of mounting orientation, change its
     *_MOTOR_DIRECTION constant above.
  */

  setLeftMotor(motorCommand);
  setRightMotor(motorCommand);
}


// =====================================================
// MPU READ
// =====================================================

bool readMPU()
{
  if (mpu.accelUpdate() != 0)
  {
    return false;
  }

  if (mpu.gyroUpdate() != 0)
  {
    return false;
  }


  ax = mpu.accelX();
  ay = mpu.accelY();
  az = mpu.accelZ();


  gx = mpu.gyroX() - gyroOffsetX;
  gy = mpu.gyroY() - gyroOffsetY;
  gz = mpu.gyroZ() - gyroOffsetZ;


  return true;
}


// =====================================================
// GYRO CALIBRATION
// =====================================================

void calibrateGyroscope()
{
  Serial.println();
  Serial.println("======================================");
  Serial.println("       GYROSCOPE CALIBRATION");
  Serial.println("======================================");

  Serial.println("KEEP ROBOT COMPLETELY STILL!");
  Serial.println();

  delay(3000);


  const int samples = 1500;

  double sumX = 0;
  double sumY = 0;
  double sumZ = 0;

  int validSamples = 0;


  for (int i = 0; i < samples; i++)
  {
    if (mpu.gyroUpdate() == 0)
    {
      sumX += mpu.gyroX();
      sumY += mpu.gyroY();
      sumZ += mpu.gyroZ();

      validSamples++;
    }

    delay(2);
  }


  if (validSamples > 0)
  {
    gyroOffsetX =
        sumX / validSamples;

    gyroOffsetY =
        sumY / validSamples;

    gyroOffsetZ =
        sumZ / validSamples;
  }


  Serial.println("Calibration complete");

  Serial.print("GX offset = ");
  Serial.println(gyroOffsetX, 4);

  Serial.print("GY offset = ");
  Serial.println(gyroOffsetY, 4);

  Serial.print("GZ offset = ");
  Serial.println(gyroOffsetZ, 4);

  Serial.println();
}


// =====================================================
// INITIAL ANGLE
// =====================================================

void initializeAngle()
{
  if (mpu.accelUpdate() == 0)
  {
    ax = mpu.accelX();
    ay = mpu.accelY();
    az = mpu.accelZ();


    /*
       Assumption:
       Forward/backward robot tilt corresponds
       to rotation around MPU Y axis.

       Therefore:
       accelerometer angle uses X and Z
       gyro rate uses GY.
    */

    accelAngle =
      atan2(
        ax,
        sqrt((ay * ay) + (az * az))
      ) * 180.0 / PI;


    balanceAngle = accelAngle;
  }


  Serial.print("Initial angle = ");
  Serial.println(balanceAngle);
}


// =====================================================
// BALANCE CONTROLLER
// =====================================================

void balanceController(float dt)
{
  if (!readMPU())
  {
    stopMotors();
    return;
  }


  // ---------------------------------------------------
  // ACCELEROMETER ANGLE
  // ---------------------------------------------------

  accelAngle =
    atan2(
      ax,
      sqrt((ay * ay) + (az * az))
    ) * 180.0 / PI;


  // ---------------------------------------------------
  // GYROSCOPE RATE
  // ---------------------------------------------------

  /*
     Pitch rotation around MPU Y axis
  */

  float gyroRate = gy;


  // ---------------------------------------------------
  // COMPLEMENTARY FILTER
  // ---------------------------------------------------

  balanceAngle =
      FILTER_ALPHA *
      (balanceAngle + gyroRate * dt)

      +

      (1.0 - FILTER_ALPHA) *
      accelAngle;


  // ---------------------------------------------------
  // FALL PROTECTION
  // ---------------------------------------------------

  if (abs(balanceAngle) > FALL_ANGLE)
  {
    robotArmed = false;

    integral = 0;
    previousError = 0;

    stopMotors();

    return;
  }


  // ---------------------------------------------------
  // AUTOMATIC ARM
  // ---------------------------------------------------

  if (!robotArmed)
  {
    stopMotors();

    if (abs(balanceAngle - balanceSetpoint)
        < ARM_ANGLE)
    {
      robotArmed = true;

      integral = 0;
      previousError = 0;

      Serial.println("BALANCE ENABLED");
    }

    return;
  }


  // ---------------------------------------------------
  // PID
  // ---------------------------------------------------

  error =
      balanceSetpoint -
      balanceAngle;


  // Integral

  integral += error * dt;


  // Integral anti-windup

  integral = constrain(
      integral,
      -50.0,
      50.0
  );


  // Derivative

  derivative =
      (error - previousError) / dt;


  // PID output

  pidOutput =
      (Kp * error)
      +
      (Ki * integral)
      +
      (Kd * derivative);


  previousError = error;


  // Limit output

  pidOutput =
      constrain(
          pidOutput,
          -MAX_PWM,
          MAX_PWM
      );


  driveBalance((int)pidOutput);
}


// =====================================================
// SERIAL COMMANDS
// =====================================================

void serialCommands()
{
  if (!Serial.available())
    return;


  String command =
      Serial.readStringUntil('\n');

  command.trim();


  // ---------------------------------------
  // Kp
  // Example:
  // P18.5
  // ---------------------------------------

  if (command.startsWith("P"))
  {
    Kp = command.substring(1).toFloat();

    Serial.print("Kp = ");
    Serial.println(Kp);
  }


  // ---------------------------------------
  // Ki
  // ---------------------------------------

  else if (command.startsWith("I"))
  {
    Ki = command.substring(1).toFloat();

    Serial.print("Ki = ");
    Serial.println(Ki);
  }


  // ---------------------------------------
  // Kd
  // ---------------------------------------

  else if (command.startsWith("D"))
  {
    Kd = command.substring(1).toFloat();

    Serial.print("Kd = ");
    Serial.println(Kd);
  }


  // ---------------------------------------
  // Setpoint
  //
  // Example:
  // A1.5
  // ---------------------------------------

  else if (command.startsWith("A"))
  {
    balanceSetpoint =
        command.substring(1).toFloat();

    Serial.print("Balance setpoint = ");
    Serial.println(balanceSetpoint);
  }


  // ---------------------------------------
  // Emergency stop
  // ---------------------------------------

  else if (command == "STOP")
  {
    robotArmed = false;

    stopMotors();

    Serial.println("ROBOT STOPPED");
  }


  // ---------------------------------------
  // Reset encoders
  // ---------------------------------------

  else if (command == "ZERO")
  {
    noInterrupts();

    leftEncoderCount = 0;
    rightEncoderCount = 0;

    interrupts();

    Serial.println("Encoder counters reset");
  }
}


// =====================================================
// DEBUG OUTPUT
// =====================================================

void printDebug()
{
  static unsigned long previousPrint = 0;


  if (millis() - previousPrint >= 100)
  {
    long leftCount;
    long rightCount;


    noInterrupts();

    leftCount = leftEncoderCount;
    rightCount = rightEncoderCount;

    interrupts();


    Serial.print("Angle: ");
    Serial.print(balanceAngle, 2);


    Serial.print(" | Acc: ");
    Serial.print(accelAngle, 2);


    Serial.print(" | PID: ");
    Serial.print(pidOutput, 1);


    Serial.print(" | L: ");
    Serial.print(leftCount);


    Serial.print(" | R: ");
    Serial.print(rightCount);


    Serial.print(" | ");

    if (robotArmed)
      Serial.println("ACTIVE");
    else
      Serial.println("SAFE");


    previousPrint = millis();
  }
}


// =====================================================
// SETUP
// =====================================================

void setup()
{
  Serial.begin(115200);

  delay(1000);


  Serial.println();
  Serial.println("======================================");
  Serial.println("               ZENO");
  Serial.println("       SELF BALANCING ROBOT");
  Serial.println("======================================");


  // ===================================================
  // MOTOR PINS
  // ===================================================

  pinMode(AIN1, OUTPUT);
  pinMode(AIN2, OUTPUT);

  pinMode(BIN1, OUTPUT);
  pinMode(BIN2, OUTPUT);

  pinMode(STBY, OUTPUT);


  digitalWrite(STBY, HIGH);


  // PWM

  ledcAttach(
      PWMA,
      PWM_FREQUENCY,
      PWM_RESOLUTION
  );

  ledcAttach(
      PWMB,
      PWM_FREQUENCY,
      PWM_RESOLUTION
  );


  stopMotors();


  // ===================================================
  // ENCODERS
  // ===================================================

  pinMode(LEFT_ENC_A, INPUT);
  pinMode(LEFT_ENC_B, INPUT);

  pinMode(RIGHT_ENC_A, INPUT);
  pinMode(RIGHT_ENC_B, INPUT);


  attachInterrupt(
      digitalPinToInterrupt(LEFT_ENC_A),
      leftEncoderISR,
      CHANGE
  );


  attachInterrupt(
      digitalPinToInterrupt(RIGHT_ENC_A),
      rightEncoderISR,
      CHANGE
  );


  // ===================================================
  // MPU9250
  // ===================================================

  Wire.begin(
      MPU_SDA,
      MPU_SCL
  );

  Wire.setClock(400000);


  mpu.setWire(&Wire);


  uint8_t accelStatus =
      mpu.beginAccel();

  uint8_t gyroStatus =
      mpu.beginGyro();


  Serial.print("Accel status: ");
  Serial.println(accelStatus);

  Serial.print("Gyro status: ");
  Serial.println(gyroStatus);


  if (accelStatus != 0 ||
      gyroStatus != 0)
  {
    Serial.println();
    Serial.println(
      "ERROR: MPU9250 initialization failed!"
    );

    while (1)
    {
      stopMotors();

      delay(1000);
    }
  }


  // ===================================================
  // CALIBRATE
  // ===================================================

  calibrateGyroscope();


  // ===================================================
  // INITIAL ANGLE
  // ===================================================

  initializeAngle();


  previousControlTime = micros();


  Serial.println();
  Serial.println("======================================");
  Serial.println("SYSTEM READY");
  Serial.println("======================================");

  Serial.println();
  Serial.println("PID tuning commands:");

  Serial.println("P20    -> set Kp");
  Serial.println("I0.1   -> set Ki");
  Serial.println("D0.8   -> set Kd");
  Serial.println("A1.2   -> balance angle");
  Serial.println("STOP   -> emergency stop");
  Serial.println("ZERO   -> reset encoders");

  Serial.println();
}


// =====================================================
// MAIN LOOP
// =====================================================

void loop()
{
  serialCommands();


  unsigned long currentTime =
      micros();


  if (currentTime - previousControlTime
      >= CONTROL_PERIOD_US)
  {
    float dt =
      (currentTime -
       previousControlTime)
      / 1000000.0;


    previousControlTime =
        currentTime;


    balanceController(dt);
  }


  printDebug();
}

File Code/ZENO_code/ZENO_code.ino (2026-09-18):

/*
  ================================================================
                  ZENO SELF-BALANCING ROBOT
  ================================================================

  Controller : ESP32 DevKit V1
  IMU        : MPU9250
  Driver     : TB6612FNG
  Motors     : 2x N20 3V 500RPM Encoder Motors

  ---------------------- PIN CONNECTIONS ---------------------------

  MPU9250
  SDA  -> GPIO 22
  SCL  -> GPIO 23

  TB6612FNG
  PWMA -> GPIO 25
  AIN1 -> GPIO 26
  AIN2 -> GPIO 27
  STBY -> GPIO 32

  BIN1 -> GPIO 14
  BIN2 -> GPIO 13
  PWMB -> GPIO 33

  Encoder currently configured
  Encoder A -> GPIO 19
  Encoder B -> GPIO 18

  ---------------------- SERIAL COMMANDS ---------------------------

  C  -> Calibrate IMU
  B  -> Enable balancing
  S  -> Stop balancing
  F  -> Move forward
  R  -> Move backward
  L  -> Turn left
  T  -> Turn right
  X  -> Stop movement
  P  -> Print PID values
  I  -> Increase Kp
  i  -> Decrease Kp
  O  -> Increase Ki
  o  -> Decrease Ki
  D  -> Increase Kd
  d  -> Decrease Kd

  ================================================================
*/

#include <Wire.h>

// ================================================================
// MPU9250
// ================================================================

#define MPU_ADDR 0x68

#define MPU_PWR_MGMT_1   0x6B
#define MPU_SMPLRT_DIV   0x19
#define MPU_CONFIG       0x1A
#define MPU_GYRO_CONFIG  0x1B
#define MPU_ACCEL_CONFIG 0x1C
#define MPU_ACCEL_XOUT_H 0x3B

// I2C
#define SDA_PIN 22
#define SCL_PIN 23


// ================================================================
// TB6612FNG
// ================================================================

// Motor A
#define PWMA 25
#define AIN1 26
#define AIN2 27

// Motor B
#define PWMB 33
#define BIN1 14
#define BIN2 13

#define STBY 32


// ================================================================
// ENCODER
// ================================================================

#define ENC_A 19
#define ENC_B 18

volatile long encoderCount = 0;


// ================================================================
// IMU VARIABLES
// ================================================================

float accX = 0;
float accY = 0;
float accZ = 0;

float gyroX = 0;
float gyroY = 0;
float gyroZ = 0;

float gyroOffsetX = 0;
float gyroOffsetY = 0;
float gyroOffsetZ = 0;

float angleOffset = 0;

float pitchAngle = 0;
float accelAngle = 0;


// ================================================================
// BALANCING PID
// ================================================================

// STARTING VALUES ONLY.
// These MUST be tuned for your actual ZENO mechanical design.

float Kp = 22.0;
float Ki = 0.0;
float Kd = 0.85;

float targetAngle = 0.0;

float error = 0;
float previousError = 0;
float integral = 0;
float derivative = 0;

float pidOutput = 0;


// ================================================================
// CONTROL VARIABLES
// ================================================================

bool calibrated = false;
bool balanceEnabled = false;

int moveCommand = 0;
int turnCommand = 0;

const int MAX_PWM = 255;

float forwardOffset = 1.5;
float turnPWM = 35;


// ================================================================
// SAFETY
// ================================================================

// If the robot falls beyond this angle motors stop.

const float FALL_ANGLE = 40.0;


// ================================================================
// FILTER
// ================================================================

float complementaryAlpha = 0.98;


// ================================================================
// TIMING
// ================================================================

unsigned long previousMicros = 0;
unsigned long serialTimer = 0;

float dt = 0;


// ================================================================
// MPU9250 FUNCTIONS
// ================================================================

void writeMPU(byte reg, byte data)
{
  Wire.beginTransmission(MPU_ADDR);
  Wire.write(reg);
  Wire.write(data);
  Wire.endTransmission();
}


// ----------------------------------------------------------------

bool testMPU()
{
  Wire.beginTransmission(MPU_ADDR);

  if (Wire.endTransmission() == 0)
  {
    return true;
  }

  return false;
}


// ----------------------------------------------------------------

void initializeMPU()
{
  Serial.println();
  Serial.println("Initializing MPU9250...");

  // Wake MPU9250
  writeMPU(MPU_PWR_MGMT_1, 0x00);
  delay(100);

  // Clock source
  writeMPU(MPU_PWR_MGMT_1, 0x01);
  delay(10);

  // Sample rate
  writeMPU(MPU_SMPLRT_DIV, 0x04);

  // Low pass filter
  writeMPU(MPU_CONFIG, 0x03);

  // Gyroscope ±250 deg/sec
  writeMPU(MPU_GYRO_CONFIG, 0x00);

  // Accelerometer ±2g
  writeMPU(MPU_ACCEL_CONFIG, 0x00);

  delay(100);

  Serial.println("MPU9250 configuration complete.");
}


// ----------------------------------------------------------------

bool readMPU()
{
  Wire.beginTransmission(MPU_ADDR);
  Wire.write(MPU_ACCEL_XOUT_H);

  if (Wire.endTransmission(false) != 0)
  {
    return false;
  }

  int received = Wire.requestFrom(
    (uint8_t)MPU_ADDR,
    (uint8_t)14,
    true
  );

  if (received != 14)
  {
    return false;
  }

  int16_t rawAX =
      ((int16_t)Wire.read() << 8) | Wire.read();

  int16_t rawAY =
      ((int16_t)Wire.read() << 8) | Wire.read();

  int16_t rawAZ =
      ((int16_t)Wire.read() << 8) | Wire.read();


  // Temperature bytes
  Wire.read();
  Wire.read();


  int16_t rawGX =
      ((int16_t)Wire.read() << 8) | Wire.read();

  int16_t rawGY =
      ((int16_t)Wire.read() << 8) | Wire.read();

  int16_t rawGZ =
      ((int16_t)Wire.read() << 8) | Wire.read();


  // Accelerometer ±2g
  accX = rawAX / 16384.0;
  accY = rawAY / 16384.0;
  accZ = rawAZ / 16384.0;


  // Gyroscope ±250 dps
  gyroX = rawGX / 131.0;
  gyroY = rawGY / 131.0;
  gyroZ = rawGZ / 131.0;


  gyroX -= gyroOffsetX;
  gyroY -= gyroOffsetY;
  gyroZ -= gyroOffsetZ;

  return true;
}


// ================================================================
// IMU CALIBRATION
// ================================================================
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
